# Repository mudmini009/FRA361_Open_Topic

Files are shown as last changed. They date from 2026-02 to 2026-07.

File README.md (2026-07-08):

---
# 🤖 MechAim-CV: Hardware-Based Physical Aimbot Using Computer Vision

A hardware-based robotic aimbot that uses real-time object detection (YOLOv5) to physically move a computer mouse. Built as an end-to-end exploration of Computer Vision, PID Control, and Inverse Kinematics.

Tested primarily in **Kovaak's Aim Trainer** to evaluate latency, tracking accuracy, and mechanical constraints without interfering with competitive multiplayer environments.

## 📺 Project Showcase

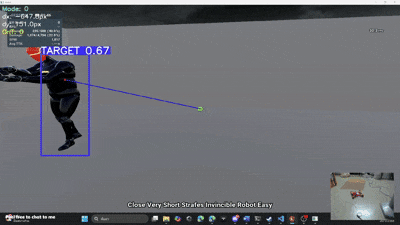
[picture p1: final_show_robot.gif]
Physical Aimbot Showcase


---

## 🚀 System Architecture

Unlike software-based aimbots, this system physically moves the mouse using a custom-built Mecanum-wheeled robot, bypassing traditional software anti-cheat mechanisms.

* **Vision System (PC):** Captures the screen, runs YOLOv5 object detection to find targets, and calculates pixel error `(dx, dy)` from the screen center.
* **Control System (PC):** A dual-axis PID controller processes the pixel error and computes the required linear velocities `(vx, vy)`. Inverse Kinematics (IK) then translates these velocities into specific speed commands for four Mecanum wheels.
* **Hardware Execution (ESP32):** The PC sends wheel speed data via Serial to an ESP32 microcontroller, which generates PWM signals for the DRV8833 motor drivers to move the physical mouse.
* **Clicking Mechanism (PC):** A Python script utilizes `pynput` to simulate realistic "pulse clicks" when the target is centered, reducing latency and simulating human input.

---

## 📁 Repository Structure

```text
📦 FRA361_Open_Topic
 ┣ 📂 archive/              # Legacy test scripts, early prototypes, and V1 learning logs
 ┣ 📂 CAD/                  # SolidWorks design files for the 3D-printed chassis
 ┣ 📂 Code_Program/         # MAIN WORKSPACE: Contains the Python vision loop & ESP32 firmware
 ┣ 📂 DATASET/              # (Ignored via .gitignore) Contains the custom 38k+ image training dataset
 ┣ 📂 documentation/        # Detailed academic reports, research papers, and reflection logs
 ┣ 📂 model_evaluation/     # Training results, confusion matrices, and metrics from Tesla V100 GPU runs
 ┣ 📂 models/               # Trained YOLOv5 weights (.pt) - Includes Small, Medium, and Large
 ┣ 📂 research_testing/     # Scripts for unit testing hardware, PWM deadzones, and software isolation
 ┣ 📜 .gitignore            # Keeps the repo clean of heavy datasets and __pycache__
 ┣ 📜 final show robot.mp4  # Showcase demonstration video
 ┣ 📜 hardware_bom.xlsx     # Bill of Materials (BOM) for the robotic chassis
 ┣ 📜 Presentation.pdf      # High-level slide deck summarizing the project engineering
 ┗ 📜 requirements.txt      # Python dependencies for the vision and control loop

```

---

## 🛠️ Getting Started

### 1. Prerequisites

* **Python 3.9+** (Tested on PyTorch 2.1 with CUDA 12.1 for RTX 3060).
* **PlatformIO** (For flashing the microcontroller).
* A generic ESP32 development board and 4x Yellow TT Motors with Mecanum wheels.

### 2. Software Installation

Clone the repository and install the required Python libraries using the provided requirements file:

```bash
git clone https://github.com/mudmini009/FRA361_Open_Topic.git
cd FRA361_Open_Topic
pip install -r requirements.txt

```

### 3. Hardware Setup (ESP32)

1. Navigate to `Code_Program/esp32/`.
2. Open the  `.cpp` firmware file in PlatformIO.
3. Connect your ESP32 via USB and upload the code.
4. Refer to `hardware_bom.xlsx` and the `CAD/` folder for assembly and wiring instructions.

### 4. Running the Aimbot

Ensure your Kovaak Aim Trainer window is open. Run the main execution loop:

```bash
cd Code_Program
python main.py

```

*Note: The script will prompt you to enter the name of the game window to bind the screen capture.*

---

## ⌨️ Controls & Modes

The system uses global keyboard hooks to allow mode switching even while the game is fully focused.

* **`Z`** : Quit application.
* **`X`** : Mode 0 (Idle / System Pause).
* **`C`** : Mode 1 (Aim Only - Tracks target but does not shoot).
* **`V`** : Mode 2 (Aim + Pulse Click - Tracks and automatically fires).

---

## 🧠 AI Models

The `models/` folder contains custom-trained YOLOv5 weights evaluated on a Tesla V100 server.

* **YOLOv5s (Small):** Best for high-speed tracking (~15ms inference).
* **YOLOv5m (Medium):** The recommended balance of accuracy and latency for PID tracking.
* **YOLOv5l (Large):** High precision, but introduces latency.
* *(Note: The YOLOv5x (X-Large) model was omitted from this repository due to file size limits and significant latency impacts >30ms that bottlenecked physical robot control)*.

---

🎓 Engineering & Academic Context

This system was originally developed and engineered as part of the **FRA361 - Open Topics** coursework within the Institute of Field Robotics (FIBO). Extensive research documentation regarding the physical prototyping iterations, empirical PWM deadzone calibrations, and dataset augmentation metrics can be found inside the `documentation/` folder and the accompanying `Presentation.pdf`.

* **Lead Engineer:** Pollapaat Suttimala
---

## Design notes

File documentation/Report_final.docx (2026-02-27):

Physical Aimbot สำหรับเกม FPS ด้วย Computer Vision

นายภนลภัส สุทธิมาลา รหัศนักศึกษา 65340500046

โครงงานนี้เป็นส่วนหนึ่งของการศึกษาตามหลักสูตร

ปริญญาวิศวกรรมศาสตรบัณฑิต สาขาวิชาวิศวกรรมหุ่นยนต์และระบบอัตโนมัติ

สถาบันวิทยาการหุ่นยนต์ภาคสนาม

มหาวิทยาลัยเทคโนโลยีพระจอมเกล้าธนบุรี

ปีการศึกษา 2567

Source Code Repository : https://github.com/mudmini009/FRA361_Open_Topic.git

# บทที่ 1 บทนำ

## 1.1 ที่มา ความสำคัญ

ในปัจจุบันเกมแนว First-Person Shooter (FPS) เป็นประเภทเกมที่ได้รับความนิยมสูง ผู้เล่นส่วนมากให้ความสำคัญกับการเล็งเป้าที่รวดเร็วและแม่นยำ ซึ่งนำไปสู่การพัฒนาเครื่องมือหรือโปรแกรมต่าง ๆ ในการฝึกฝนทักษะการเล็ง เช่น Aim Training Software เป็นต้น อย่างไรก็ตาม กระบวนการฝึกเล็งดังกล่าวยังต้องอาศัยการขยับเมาส์ของผู้เล่นเองเป็นหลัก ซึ่งอาจเกิดข้อจำกัดด้านความแม่นยำและความสม่ำเสมอในการเคลื่อนที่ของมือมนุษย์

โครงงานนี้จึงมีแนวคิดในการพัฒนาระบบ "Physical Aimbot" โดยนำหลักการทางด้านวิศวกรรมหุ่นยนต์ (Robotics) และการประมวลผลภาพ (Computer Vision) มาผสมผสานกัน เพื่อสร้างหุ่นยนต์ที่สามารถควบคุมเมาส์จริงบนพื้นผิวจริงได้อย่างแม่นยำและอัตโนมัติ ผ่านการตรวจจับตำแหน่งเป้าหมายบนหน้าจอจากภาพหรือวิดีโอที่ประมวลผลด้วยโมเดล Machine Learning ประเภท Object Detection เช่น YOLO (You Only Look Once) โดยมีวัตถุประสงค์หลักคือ เพื่อศึกษาความเป็นไปได้ในการผสานเทคโนโลยีหุ่นยนต์และ Computer Vision รวมทั้งสร้างความรู้พื้นฐานและประสบการณ์ในการออกแบบและพัฒนาระบบที่มีทั้งองค์ประกอบทางด้าน Software และ Hardware มากกว่าจะมุ่งเน้นการนำไปใช้เพื่อประโยชน์เชิงแข่งขันหรือเชิงโกงภายในเกม

## 1.2 ประโยคปัญหางานวิจัย (Problem Statement)

ในการเล็งเป้าหมายในเกม FPS หรือโปรแกรมฝึกเล็งที่ต้องการความแม่นยำสูง ผู้เล่นมักประสบปัญหาในการควบคุมการเคลื่อนที่ของเมาส์ให้แม่นยำและรวดเร็ว เนื่องจากการปรับมุมและตำแหน่งของเมาส์ซ้ำ ๆ ส่งผลให้เสียเวลาและลดประสิทธิภาพในการเล่น โครงงานนี้จึงมุ่งสำรวจและพัฒนาระบบการควบคุมการเคลื่อนที่ของเมาส์ด้วยกลไกหุ่นยนต์และการประมวลผลภาพ (Computer Vision) แบบเรียลไทม์ เพื่อสร้างระบบช่วยเล็งที่สามารถตรวจจับเป้าหมายบนหน้าจอและสั่งให้หุ่นยนต์เคลื่อนที่เมาส์ให้ตรงตามเป้าหมายได้อย่างแม่นยำและอัตโนมัติ ทั้งนี้เพื่อเพิ่มความต่อเนื่องในการเล่นและเป็นการศึกษาการผสานเทคโนโลยี Robotics กับ Computer Vision ให้เกิดเป็นรูปธรรม

## 1.3 ผลผลิตและผลลัพธ์ (Outputs and Outcomes)

### ผลผลิต

1. ต้นแบบหุ่นยนต์ (Robot Prototype) ที่สามารถควบคุมและเคลื่อนที่ของเมาส์จริงบนพื้นผิว เพื่อเล็งไปยังตำแหน่งเป้าหมายที่ระบุจากระบบตรวจจับภาพ

2. โมเดล Machine Learning (YOLO-based Object Detection Model) ที่สามารถตรวจจับและระบุตำแหน่งเป้าหมายจากภาพหรือวิดีโอแบบเรียลไทม์ ในโปรแกรมฝึกเล็ง (Aim Training Software) หรือเกม FPS

### ผลลัพธ์

1. ความรู้และความเข้าใจเชิงลึก เกี่ยวกับการผสมผสานระหว่างเทคโนโลยี Robotics และ Computer Vision ในการประยุกต์ใช้สำหรับการควบคุมอุปกรณ์เชิงกายภาพ

2. แนวทางหรือกรอบการทำงาน (Framework) ในการพัฒนาระบบช่วยเล็งแบบกายภาพ (Physical Aiming Assistant) ที่สามารถนำไปต่อยอดหรือปรับปรุงในการศึกษาหรือวิจัยอื่น ๆ ในอนาคตได้

## 1.4 ความต้องการของระบบ (Requirements)

1. ระบบต้องสามารถจับภาพหน้าจอหรือรับข้อมูลจากโปรแกรมฝึกเล็งใน Kovaak โดยใช้ Python library สำหรับการจับภาพ เพื่อระบุพิกัดเป้าหมาย

2. ระบบหุ่นยนต์ต้องสามารถเคลื่อนที่ได้อย่างมีประสิทธิภาพในการเล็งและปรับตำแหน่งเมาส์ตามข้อมูลที่ได้รับ โดยใช้มอเตอร์แบบ Yellow TT motor ที่ติดกับล้อ Mecanum

3. ในอนาคตจะพัฒนาโมดูลสำหรับการส่งสัญญาณคลิก โดยใช้การสื่อสารผ่าน ESP32 Bluetooth ที่เชื่อมต่อกับ PC เพื่อส่งข้อมูลการคลิก

4. ใช้ซอฟต์แวร์และฮาร์ดแวร์ที่หาได้ทั่วไป เช่น Logitech G Pro X Superlight, ESP32 สำหรับการสื่อสาร Bluetooth, และ Python library สำหรับการจับภาพหน้าจอ (แทนการใช้ Capture Card)

## 1.5 ขอบเขตของงานวิจัย (Scopes)

1.ใช้โปรแกรมฝึกเล็ง (Kovaak) เป็นหลักในการเก็บข้อมูลภาพหรือวิดีโอ เพื่อนำมาประมวลผลด้วยโมเดล Machine Learning ในการระบุตำแหน่งเป้าหมาย

2.มุ่งเน้นการทดสอบประสิทธิภาพของระบบ โดยวัดผลจากคะแนน (Score) ที่ได้จากแต่ละ Scenario ในโปรแกรม Kovaak เป็นหลัก เช่น คะแนนรวม (Total Score), ความแม่นยำ (Accuracy), เปอร์เซ็นต์การยิงโดน (Percent Hit), จำนวนเป้าหมายที่ยิงโดน (Targets Hit), จำนวนเป้าหมายที่พลาด (Targets Missed), และข้อมูลเชิงสถิติอื่นๆ ที่โปรแกรมมีให้ เพื่อศึกษาความสามารถในการเล็งเป้าของระบบหุ่นยนต์อย่างชัดเจนและวัดผลได้

3.ในขั้นนี้จะยังไม่เน้นเก็บสถิติเรื่องความเร็วในการตอบสนอง (Latency) หรือรายละเอียดด้านเวลาเป็นหลัก

4.โครงงานนี้มีจุดประสงค์เพื่อศึกษาและพัฒนาองค์ความรู้ในการประยุกต์ใช้ Robotics และ Computer Vision เท่านั้น ไม่มีเจตนาที่จะนำไปใช้งานเพื่อประโยชน์เชิงแข่งขันจริงหรือเพื่อการโกงเกม

## 1.6 ข้อกำหนดของงานวิจัย (Assumptions)

1. สภาพแวดล้อม (Environment) ที่ใช้ในการทดสอบ เช่น ความละเอียดหน้าจอ (Screen Resolution) และการตั้งค่ากราฟิก (Graphic Settings) ในโปรแกรม Kovaak จะถูกกำหนดให้มีค่าคงที่และไม่เปลี่ยนแปลงตลอดช่วงการทดลอง เพื่อความสม่ำเสมอในการเก็บข้อมูล

2. ผู้วิจัยสามารถปรับค่าความไวของเมาส์ (Mouse Sensitivity) และการตั้งค่าอื่น ๆ ที่เกี่ยวข้องได้ตามความเหมาะสม เพื่อให้ตรงกับเงื่อนไขและความต้องการในการทดลองร่วมกับโปรแกรม Kovaak

## 1.7 ขั้นตอนการดำเนินงาน

1. เก็บข้อมูลและสร้าง Dataset

1.1. บันทึกการเล่นโปรแกรม Kovaak (Scenarios ต่างๆ เช่น Tracking และ Dynamic Clicking)

1.2. ใช้ OpenCV ดึงภาพจากวิดีโอที่บันทึกไว้ นำไปทำ Label และ Augmentation

2. พัฒนาและฝึกโมเดล Machine Learning

2.1. บันทึกการเล่นโปรแกรม Kovaak (Scenarios ต่างๆ เช่น Tracking และ Dynamic Clicking)

2.2. ใช้ OpenCV ดึงภาพจากวิดีโอที่บันทึกไว้ นำไปทำ Label และ Augmentation

3. ศึกษาและคัดเลือกฮาร์ดแวร์

3.1. สำรวจตัวเลือกและตัดสินใจเลือกใช้ล้อ Mecanum และมอเตอร์ประเภท Yellow TT motor เนื่องจากข้อจำกัดด้านงบประมาณ

3.2. ออกแบบระบบจ่ายไฟโดยใช้แบตเตอรี่ 18650 สองก้อน พร้อมวงจรควบคุมแรงดัน (XL4016E1)

4. ออกแบบและเขียนแบบ CAD

4.1. ออกแบบโครงสร้างหุ่นยนต์และส่วนยึดอุปกรณ์ทั้งหมด โดยใช้โปรแกรม CAD เพื่อจัดวางตำแหน่งของมอเตอร์, ล้อ, ESP32 และส่วนประกอบอื่นๆ

5. สร้างต้นแบบหุ่นยนต์ (Prototype)

5.1. ประกอบวงจรและอุปกรณ์ต่างๆ ตามแบบ CAD

5.2. ทดลองระบบเบื้องต้นเพื่อทดสอบการเคลื่อนที่ของหุ่นยนต์ (ยังไม่รวมการเชื่อมต่อกับระบบ Software)

6. ผสานระบบ (Integration)

6.1. เขียนโปรแกรม Python เพื่อจับภาพหน้าจอจากโปรแกรม Kovaak แล้วส่งไปยังโมเดล YOLOv5 ที่ฝึกไว้

6.2. ส่งค่าตำแหน่งเป้าหมายที่ได้จากการตรวจจับไปยัง ESP32 ผ่าน PySerial เพื่อควบคุมการเคลื่อนที่ของหุ่นยนต์

6.3. ใช้ ESP32 Bluetooth ส่งข้อมูลคลิกกลับไปยัง PC (พัฒนาเพิ่มเติมในอนาคต)

7. ทดสอบและปรับแต่งระบบ

7.1. ทดสอบการทำงานจริงโดยวัดผลจากคะแนน (Scores) และความแม่นยำ (Accuracy) จาก Kovaak

7.2. วิเคราะห์ผลเบื้องต้น และวางแผนเพิ่มประสิทธิภาพ เช่น การปรับปรุง Dataset, การ Train โมเดลเพิ่มเติม, หรือปรับแต่ง Hardware

# บทที่ 2 ทฤษฎี/งานวิจัย/การศึกษาที่เกี่ยวข้อง

## 2.1Computer Vision สำหรับ Object Detection

การตรวจจับวัตถุ (Object Detection) เป็นเทคนิคในวิทยาการคอมพิวเตอร์ที่ใช้ในการระบุและกำหนดตำแหน่งของวัตถุภายในภาพหรือวิดีโอ โดยทั่วไปจะใช้กรอบสี่เหลี่ยมล้อมรอบวัตถุที่ตรวจพบ

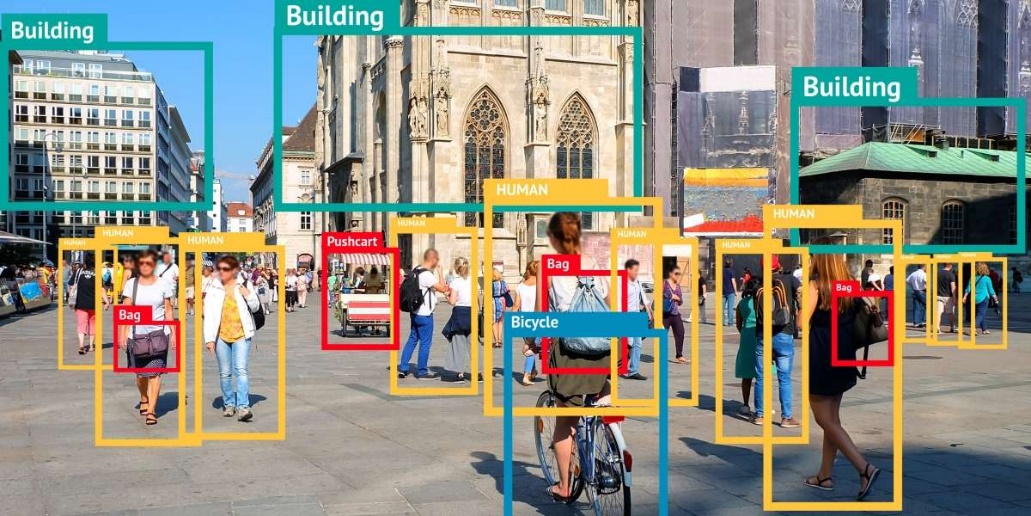
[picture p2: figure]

### 2.1.1 หลักการทำงานพื้นฐานของ YOLO (You Only Look Once)

YOLO ทำงานโดยแบ่งภาพอินพุตออกเป็นกริดขนาด S x S และสำหรับแต่ละเซลล์ในกริดนั้น โมเดลจะทำนาย B กล่องขอบเขต (bounding boxes) พร้อมกับคะแนนความเชื่อมั่น (confidence scores) ที่บ่งบอกถึงความน่าจะเป็นที่กล่องนั้นจะมีวัตถุอยู่ และความแม่นยำของกล่องที่ทำนาย นอกจากนี้ แต่ละเซลล์ยังทำนายความน่าจะเป็นแบบมีเงื่อนไขสำหรับแต่ละคลาสของวัตถุ โดยอิงตามความน่าจะเป็นที่เซลล์นั้นมีวัตถุอยู่ การทำนายทั้งหมดนี้เกิดขึ้นพร้อมกันในการประมวลผลเพียงครั้งเดียว ทำให้ YOLO มีความเร็วสูงในการตรวจจับวัตถุ

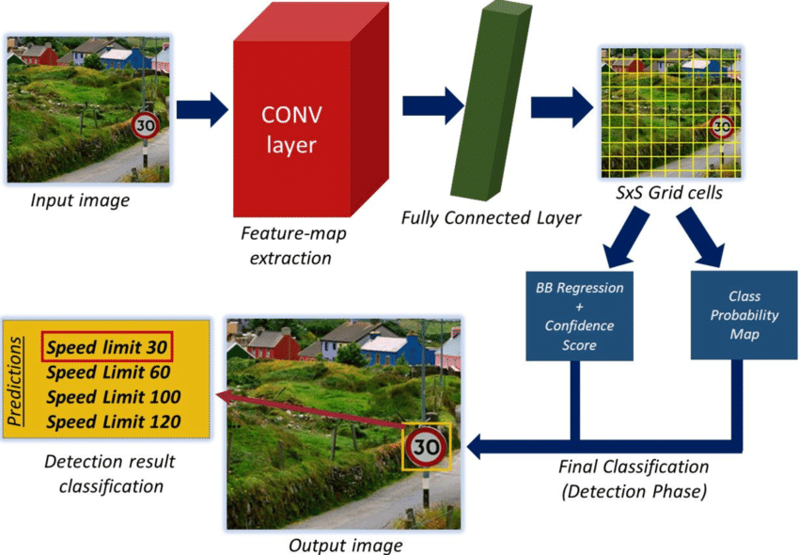
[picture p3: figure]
Object detection and classification process in YOLO. | Download Scientific Diagram

1. โครงสร้างโมเดล YOLO

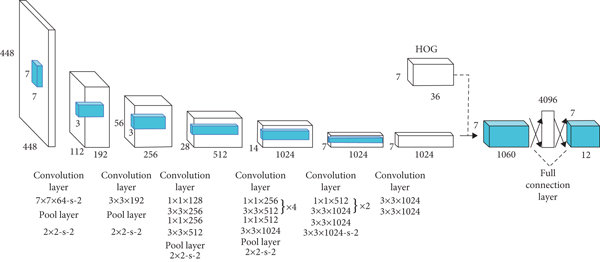
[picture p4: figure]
Yolo model convolution layer network structure diagram. | Download Scientific Diagram

โครงสร้างของ YOLO ประกอบด้วยเลเยอร์คอนโวลูชันหลายชั้นที่ใช้ในการดึงคุณลักษณะจากภาพอินพุต ตามด้วยเลเยอร์ที่เชื่อมต่อกันอย่างสมบูรณ์ (fully connected layers) ที่ใช้ในการทำนายตำแหน่งของกล่องขอบเขตและความน่าจะเป็นของคลาสวัตถุ โครงสร้างนี้ช่วยให้โมเดลสามารถเรียนรู้การแทนภาพในระดับสูงและทำการทำนายได้อย่างแม่นยำ

2. กระบวนการตรวจจับภาพและหลักการทำงานของ YOLO

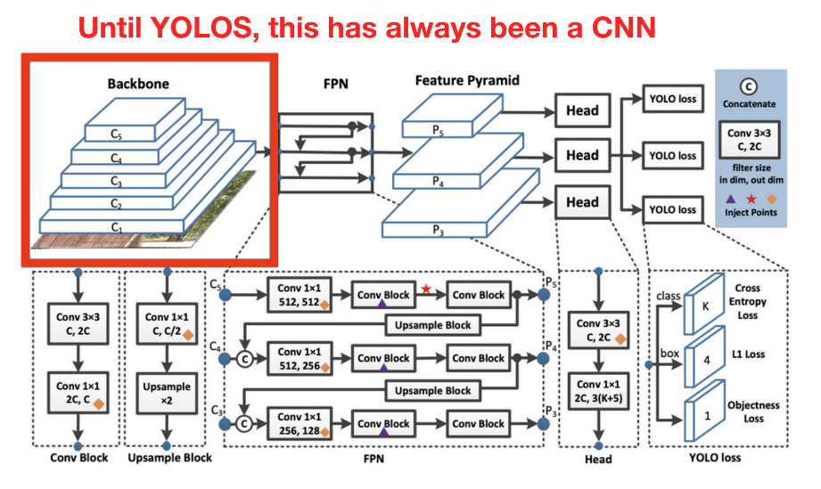
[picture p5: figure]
What is YOLOS? What's New in the Model?

  a. การแบ่งภาพเป็นกริด: ภาพอินพุตจะถูกแบ่งออกเป็นกริดขนาด S x S โดยแต่ละเซลล์ในกริดจะรับผิดชอบในการทำนายวัตถุที่มีศูนย์กลางอยู่ในเซลล์นั้น
  b. การทำนายกล่องขอบเขตและคะแนนความเชื่อมั่น: สำหรับแต่ละเซลล์ โมเดลจะทำนาย กล่องขอบเขต พร้อมกับคะแนนความเชื่อมั่นที่บ่งบอกถึงความน่าจะเป็นที่กล่องนั้นจะมีวัตถุอยู่ และความแม่นยำของกล่องที่ทำนาย
  c. การทำนายความน่าจะเป็นของคลาสวัตถุ: โมเดลจะทำนายความน่าจะเป็นแบบมีเงื่อนไขสำหรับแต่ละคลาสของวัตถุ โดยอิงตามความน่าจะเป็นที่เซลล์นั้นมีวัตถุอยู่
  d. การคูณคะแนนความเชื่อมั่นกับความน่าจะเป็นของคลาส: คะแนนความเชื่อมั่นจะถูกคูณกับความน่าจะเป็นของคลาสเพื่อให้ได้คะแนนสุดท้ายสำหรับแต่ละกล่องขอบเขต
  e. การกรองกล่องขอบเขต: ใช้เทคนิค Non-Maximum Suppression (NMS) เพื่อลบกล่องขอบเขตที่ซ้ำซ้อนและเก็บเฉพาะกล่องที่มีคะแนนสูงสุดสำหรับแต่ละวัตถุ

### 2.1.2 การเปรียบเทียบรุ่น YOLO (YOLO Version Comparison)

ในงานนี้ เราเน้นการใช้โมเดล YOLOv5 ซึ่งมีหลายเวอร์ชันที่แตกต่างกันในเรื่องของขนาดและประสิทธิภาพ เราสามารถแบ่งเวอร์ชันหลัก ๆ ได้ดังนี้:

1. YOLOv5s (Small)
  - ข้อดี:
    - มีขนาดเล็ก ใช้ทรัพยากรน้อย
    - ประมวลผลได้รวดเร็ว เหมาะกับงานที่ต้องการการตอบสนองแบบเรียลไทม์ เช่น การตรวจจับเป้าหมายในโปรแกรม Aim Training (Kovaak)
  - ข้อเสีย:
    - ความแม่นยำอาจต่ำกว่าเมื่อเทียบกับเวอร์ชันที่มีขนาดใหญ่กว่า
2. YOLOv5m (Medium)
  - ข้อดี:
    - ให้ความแม่นยำสูงขึ้นจาก YOLOv5s ด้วยจำนวนพารามิเตอร์ที่เพิ่มขึ้น
    - ยังสามารถประมวลผลแบบเรียลไทม์ได้ดีในระบบที่มีฮาร์ดแวร์ประสิทธิภาพสูง
  - ข้อเสีย:
    - ใช้ทรัพยากรมากขึ้น และอาจมีความช้ากว่า YOLOv5s เล็กน้อย
3. YOLOv5l (Large) และ YOLOv5x (Extra Large)
  - ข้อดี:
    - ให้ความแม่นยำสูงสุด เนื่องจากมีจำนวนพารามิเตอร์มากที่สุด
  - ข้อเสีย:
    - ประมวลผลช้ากว่าและต้องการทรัพยากรระบบที่สูงขึ้น ซึ่งอาจไม่เหมาะกับงานที่ต้องการความเร็วแบบเรียลไทม์ในสภาพแวดล้อมที่มีข้อจำกัดด้านทรัพยากร

สำหรับโครงการนี้ เราเริ่มต้นด้วย YOLOv5s (Small) เนื่องจากมีความเร็วสูงและเหมาะสมกับการทดลองเบื้องต้นในระบบ Aim Training (Kovaak) อย่างไรก็ตาม ด้วยประสิทธิภาพของ PC ที่มีอยู่ (สามารถรันได้ 200+ FPS) ในอนาคตจึงมีความเป็นไปได้ที่จะปรับปรุงและฝึกเพิ่มเติมโดยพิจารณาให้เหมาะสมกับข้อจำกัดของฮาร์ดแวร์และลักษณะของงาน เช่น หากต้องการตรวจจับอย่างรวดเร็วและใช้งานร่วมกับระบบที่มีข้อจำกัดด้าน latency อาจเลือกใช้ YOLOv5s หรือ m ในขณะที่หากระบบสามารถรองรับการประมวลผลที่ช้าลงได้และต้องการความแม่นยำสูง YOLOv5l หรือ x ก็เป็นทางเลือกที่เหมาะสม

## 2.2 Robotics และการควบคุมการเคลื่อนที่

### 2.2.1 Omni Wheels และ Mecanum Wheels

ในการออกแบบระบบเคลื่อนที่สำหรับหุ่นยนต์ที่ควบคุมเมาส์ในงาน Physical Aimbot มีล้อสองแบบที่มักถูกนำมาใช้ ได้แก่ Omni Wheels และ Mecanum Wheels:

  - Omni Wheels:
    - หลักการ: ล้อ Omni มีแผ่นสัมผัสที่สามารถหมุนได้ในแนวตั้งและมีล้อเล็กติดอยู่รอบๆ ซึ่งช่วยให้เคลื่อนที่ได้ในทิศทางหลายทิศทาง
    - ข้อดี: ให้ความสามารถในการเคลื่อนที่แบบ holonomic (เคลื่อนที่ในทุกทิศทาง)
    - ข้อเสีย: โดยทั่วไปราคาแพงกว่าแบบอื่นถึง 4–5 เท่า ทำให้ไม่เหมาะสำหรับงานที่มีข้อจำกัดด้านงบประมาณ
  - Mecanum Wheels:
    - หลักการ: ล้อ Mecanum มีลูกกลิ้งติดอยู่ที่ขอบล้อในมุมเอียง ช่วยให้สามารถเคลื่อนที่แบบ omnidirectional ได้ด้วยการควบคุมความเร็วของแต่ละล้อแยกกัน
    - ข้อดี: ราคาถูกกว่า Omni Wheels อย่างมาก, ให้ความสามารถในการเคลื่อนที่แบบหลายทิศทางได้ดีเพียงพอสำหรับงานควบคุมเมาส์ในระบบ Physical Aimbot
    - ข้อเสีย: การควบคุมอาจซับซ้อนกว่าเล็กน้อยเนื่องจากต้องคำนวณการเคลื่อนที่ที่สัมพันธ์กันของล้อทั้งหมด

สาเหตุที่เลือก Mecanum Wheels:

เนื่องจากข้อจำกัดด้านงบประมาณ โดย Omni Wheels มีราคาสูงถึง 4–5 เท่าของ Mecanum Wheels ทำให้การเลือกใช้ Mecanum Wheels เป็นทางเลือกที่ประหยัดและยังคงให้ประสิทธิภาพในการเคลื่อนที่ที่เพียงพอสำหรับการควบคุมเมาส์ในโครงงานนี้

### 2.2.2 ทฤษฎี Inverse Kinematics สำหรับล้อ Mecanum

การควบคุมการเคลื่อนที่ในหุ่นยนต์ที่ใช้ล้อ Mecanum ต้องอาศัยหลักการของ Inverse Kinematics ซึ่งเป็นการคำนวณหาความเร็วและทิศทางของแต่ละล้อจากคำสั่งการเคลื่อนที่ที่ต้องการ (เช่น การเล็งเป้าหมาย)

- หลักการคำนวณ: สำหรับหุ่นยนต์ที่ใช้ล้อ Mecanum จำนวน 4 ตัว เราสามารถคำนวณความเร็วของแต่ละล้อจากความต้องการเคลื่อนที่ในแกน X (Vx), แกน Y (Vy) และการหมุน (angular velocity, ω) ได้ดังนี้:
  - ความเร็วล้อหน้าซ้าย (V_FL) = Vx - Vy - (L + W) * ω
  - ความเร็วล้อหน้าขวา (V_FR) = Vx + Vy + (L + W) * ω
  - ความเร็วล้อหลังซ้าย (V_RL) = Vx + Vy - (L + W) * ω
  - ความเร็วล้อหลังขวา (V_RR) = Vx - Vy + (L + W) * ω โดยที่:
    - Vx: ความเร็วในแนวแกน X
    - Vy: ความเร็วในแนวแกน Y
    - ω: ความเร็วเชิงมุม (การหมุน)
    - L: ระยะจากจุดศูนย์กลางไปยังล้อในแนวตั้ง
    - W: ระยะจากจุดศูนย์กลางไปยังล้อในแนวนอน
- แนวคิดเบื้องต้นในการควบคุม: เมื่อระบบ Computer Vision ตรวจจับเป้าหมายแล้ว ระบบจะคำนวณตำแหน่งเป้าหมายที่ต้องเล็ง จากนั้นใช้ Inverse Kinematics ในการแปลงคำสั่งเคลื่อนที่ (เช่น ค่า Vx, Vy, ω) ไปเป็นความเร็วที่แต่ละล้อควรหมุนเพื่อให้หุ่นยนต์เคลื่อนที่ไปในทิศทางที่ต้องการได้อย่างแม่นยำ การคำนวณเหล่านี้ช่วยให้ระบบสามารถปรับตำแหน่งเมาส์ให้ตรงกับเป้าหมายได้โดยอัตโนมัติ

### 2.2.3 PID Controller สำหรับการควบคุมความเร็วของมอเตอร์

ในการควบคุมความเร็วหรือทิศทางของมอเตอร์ให้แม่นยำในระบบหุ่นยนต์ มักนิยมใช้ PID Controller (Proportional–Integral–Derivative) ซึ่งเป็นการควบคุมแบบ Feedback ที่สามารถลดความคลาดเคลื่อน (error) ระหว่าง "ค่าที่ต้องการ" (Setpoint) และ "ค่าที่เกิดขึ้นจริง" (Measured Value) ได้อย่างมีประสิทธิภาพ

แนวคิดพื้นฐานของ PID

PID ประกอบด้วยสามส่วนหลัก ดังนี้:

- P (Proportional): เป็นส่วนที่ตอบสนองต่อค่า error ปัจจุบัน โดยมีค่าสัดส่วนเป็นตัวคูณ P_out = Kp * e(t)
- I (Integral): เป็นส่วนที่รวมสะสมค่า error ย้อนหลัง เพื่อกำจัดค่า steady-state error I_out = Ki * ∫ e(t) dt
- D (Derivative): เป็นส่วนที่ตอบสนองต่อการเปลี่ยนแปลงของ error เพื่อช่วยลดการ overshoot และทำให้ระบบมีความเสถียรมากขึ้น

D_out = Kd * de(t)/dt

ผลรวมของทั้งสามส่วนคือสัญญาณควบคุมที่ใช้ส่งไปยังมอเตอร์:

u(t) = P_out + I_out + D_out

หรือรวมในสมการเดียว:

u(t) = Kp * e(t) + Ki * ∫ e(t) dt + Kd * de(t)/dt

โดยที่:

- u(t) = ค่าคำสั่งควบคุมที่ส่งออก
- e(t) = ค่า error = ค่าที่ต้องการ - ค่าที่วัดได้
- Kp, Ki, Kd = ค่าพารามิเตอร์ของ PID ซึ่งต้องทำการจูนให้เหมาะสมกับระบบ

การประยุกต์ใช้กับโครงงาน Physical Aimbot

ในโครงงานนี้ PID ถูกออกแบบมาเพื่อใช้ควบคุม ความเร็วของมอเตอร์แต่ละตัว เพื่อเคลื่อนที่หุ่นยนต์ให้ไปยังตำแหน่งที่ตรวจจับได้จากระบบ Vision โดยมีขั้นตอนดังนี้:

1. ระบบตรวจจับภาพจะระบุ ตำแหน่งเป้าหมาย (Target) บนหน้าจอ
2. คำนวณตำแหน่งเป้าหมายเทียบกับจุดศูนย์กลางของหน้าจอ เพื่อหา ค่าความคลาดเคลื่อน (error) ทั้งในแนวระยะ (Distance) และมุม (Angle)
3. นำค่า error ที่ได้เข้าสู่ฟังก์ชัน PID เพื่อคำนวณ "ความเร็วของแต่ละล้อ" ที่จะทำให้หุ่นยนต์เคลื่อนที่เข้าหาเป้าหมายอย่างแม่นยำ

ระบบนี้สามารถใช้ distance เป็นค่าความห่างจากเป้าหมาย และ angle เป็นทิศทางเปรียบเทียบกับแนวตั้งฉากของหุ่นยนต์ ทำให้สามารถนำทั้งสองค่ามาควบคุม PID แบบแยกแกนได้ หรือแบบรวมก็ได้ ขึ้นอยู่กับกลยุทธ์การควบคุม

การตั้งค่าพารามิเตอร์ PID (PID Tuning)

การตั้งค่าค่า Kp, Ki, Kd ที่เหมาะสมเป็นขั้นตอนที่สำคัญมาก โดยวิธีที่นิยมคือ Manual Tuning หรือ "trial-and-error" โดย:

1. เริ่มจาก Ki และ Kd = 0
2. เพิ่ม Kp ทีละน้อยจนระบบเริ่มตอบสนอง
3. เพิ่ม Ki เพื่อแก้ปัญหา steady-state error
4. เพิ่ม Kd เพื่อช่วยลด overshoot และเพิ่มความเสถียร

ในกรณีของโครงงานนี้ เนื่องจากไม่มี encoder feedback เพื่อวัดความเร็วของล้อจริง จึงมีการใช้ “distance to target” หรือ “angle to target” จาก Vision เป็น input แทน โดยจะต้องสังเกตพฤติกรรมของหุ่นยนต์เพื่อทำการจูนค่า PID ให้เหมาะสม

## 2.3 Hardware และการสื่อสารข้อมูล

### 2.3.1 ESP32 Microcontroller

เราเลือกใช้ ESP32 เนื่องจากมีคุณสมบัติที่โดดเด่นหลายประการที่สอดคล้องกับความต้องการของโครงงานนี้

- ความเร็วและประสิทธิภาพสูง: ESP32 สามารถประมวลผลคำสั่งและสื่อสารได้อย่างรวดเร็ว ทำให้รองรับงานที่ต้องการการตอบสนองแบบเรียลไทม์
- การเชื่อมต่อแบบ WiFi และ Bluetooth: การมีทั้ง WiFi และ Bluetooth ในตัวช่วยให้เราสามารถเชื่อมต่อกับ PC ผ่าน WiFi หรือใช้ Bluetooth สำหรับส่งคำสั่งการคลิกโดยตรง ซึ่งจะช่วยลดความซับซ้อนของโมดูลคลิกแยกต่างหาก
- ความยืดหยุ่นในการประมวลผล Inverse Kinematics: ระบบสามารถเลือกที่จะคำนวณ Inverse Kinematics บนตัว ESP32 เอง หรือรับค่าที่คำนวณจาก PC (เช่น ค่า Distance, Degree และ Shooting command) ขึ้นอยู่กับประสิทธิภาพของแต่ละหน่วย เราสามารถปรับเปลี่ยนวิธีการส่งข้อมูลได้โดยพิจารณาจากความเร็วในการคำนวณของ PC เทียบกับ ESP32

### 2.3.2 การสื่อสารข้อมูลผ่าน PySerial

สำหรับการส่งข้อมูลระหว่างคอมพิวเตอร์และ ESP32 เราใช้การสื่อสารผ่าน PySerial ด้วยข้อดีดังนี้:

- การเชื่อมต่อที่ง่าย: PySerial ช่วยให้การส่งข้อมูลระหว่าง PC กับ ESP32 เป็นไปอย่างราบรื่น โดยไม่ต้องใช้ฮาร์ดแวร์เพิ่มเติม
- ประเภทของข้อมูลที่ส่ง:
  - Distance: ระยะห่างระหว่างตำแหน่งปัจจุบันกับเป้าหมายที่คำนวณได้
  - Degree: มุมที่เป้าหมายอยู่ในระบบพิกัด
  - Shooting Command: คำสั่งยิงที่จะส่งไปยัง ESP32 เมื่อเป้าหมายอยู่ในขอบเขตที่กำหนด
- กระบวนการส่งข้อมูล:
  - หากการคำนวณ Inverse Kinematics ถูกดำเนินการบน PC เราจะส่งข้อมูลที่คำนวณแล้ว (Distance, Degree) พร้อมกับคำสั่งยิง (Shooting command) ไปยัง ESP32
  - ในทางกลับกัน หาก ESP32 มีความสามารถในการคำนวณ Inverse Kinematics ได้เร็วเพียงพอ ระบบจะรับข้อมูลพื้นฐานจาก PC (เช่น ตำแหน่งเป้าหมาย) แล้วคำนวณค่า Distance, Degree และตัดสินใจส่งคำสั่งยิงภายในตัวเอง

### 2.3.3 Motor และ Driver

ในการขับเคลื่อนระบบหุ่นยนต์ เราเลือกใช้ Yellow TT Motor ร่วมกับ DRV8833 Motor Driver ด้วยเหตุผลดังนี้:

- Yellow TT Motor:
  - ร้านค้าที่มีจำหน่ายมีให้เลือกเพียง 2 แบบคือ 1:150 และ 1:48 สำหรับเกียร์
  - เนื่องจากหุ่นยนต์ของเราเบา (ใช้สำหรับเคลื่อนที่เมาส์ที่มีน้ำหนักต่ำ) เราจึงเลือกใช้เกียร์ 1:48 เพื่อให้ได้ความเร็วที่สูงขึ้น แม้ว่าแรงบิด (torque) จะน้อยลง แต่สำหรับงานนี้ ความเร็วในการตอบสนองและการเคลื่อนที่เป็นสิ่งที่สำคัญกว่า
  - โดยจาก Datasheet ของร้านค้า Yellow TT Motor 1:48 มีค่าแรงบิดประมาณ 1.5 kg⋅cm ซึ่งเมื่อนำมาคำนวณเป็นแรงขับเคลื่อนบนพื้นราบ สามารถวิเคราะห์ได้ดังนี้:

การประมาณแรงขับเคลื่อน (Force Calculation):

Torque (τ) = 1.5 kg⋅cm = 0.147 N⋅m
รัศมีล้อ (r) = 48 mm / 2 = 0.024 m
แรง (F) ที่ปลายล้อ = τ / r
= 0.147 / 0.024 ≈ 6.125 N ต่อล้อ

หากใช้ล้อทั้ง 4 ล้อขับเคลื่อนพร้อมกัน:

แรงรวม ≈ 4 × 6.125 = 24.5 N

และจากสมการ F = ma ⇒ a = F/m

การประมาณน้ำหนักหุ่นยนต์:

องค์ประกอบ | ประมาณน้ำหนัก
เมาส์ Logitech G Pro X | ~70 g
แบตเตอรี่ 18650 × 2 | ~90 g
ESP32 + XL4016 | ~40 g
โครง 3D print + มอเตอร์ | ~300 g
รวม | ~500 g (0.5 kg)

น้ำหนักหุ่นยนต์ประมาณ 0.5 kg ⇒ ต้องการแรงเพื่อเริ่มเคลื่อนที่ ≈ μmg
โดยที่:

μ = ค่าสัมประสิทธิ์แรงเสียดทานระหว่าง mouse feet กับพื้น ≈ 0.3–0.5 (Corepad Air)

g = 9.81 m/s²

⇒ F_friction ≈ 0.4 × 0.5 × 9.81 ≈ 1.96 N

เมื่อเทียบกับแรงขับเคลื่อน ≈ 24.5 N (รวมทุกล้อ)
→ มีแรงมากเพียงพอในทางทฤษฎี สำหรับการเคลื่อนที่ แม้จะเผื่อการสูญเสียในระบบ

- DRV8833 Motor Driver:
  - เป็นตัวควบคุมมอเตอร์ที่มีขนาดกะทัดรัด น้ำหนักเบา และรองรับการทำงานของมอเตอร์ในระดับแรงดันที่เหมาะสมสำหรับระบบของเรา

### 2.3.3.1 ข้อสังเกตเพิ่มเติมจากการใช้งานจริงของมอเตอร์ Yellow TT (1:48)

ผู้วิจัยจึงตัดสินใจเลือกใช้ มอเตอร์เกียร์ 1:48 เนื่องจากตัวหุ่นยนต์มีน้ำหนักรวมไม่มาก (ใช้เพียงเมาส์, ESP32, แบตเตอรี่ และโครงพลาสติก) โดยมีเป้าหมายให้หุ่นยนต์สามารถตอบสนองต่อคำสั่งเล็งเป้าได้เร็วและลื่นไหล

อย่างไรก็ตาม จากการทดสอบจริงในระยะหลัง พบว่าอัตราทด 1:48 อาจ ไม่เหมาะสมในด้านความแม่นยำในความเร็วต่ำ เพราะล้อจะเริ่มหมุนเมื่อได้รับแรงมากพอเท่านั้น เนื่องจากแรงบิดเริ่มต้นต่ำ ทำให้ไม่สามารถควบคุมการเคลื่อนไหวแบบละเอียด (เช่น เล็งเป้าแบบละเอียดยิบหรือแก้ไขเป้าเล็ก ๆ) ได้ดีนัก

ปัญหาที่พบ:

- ล้อมี Deadzone ขนาดใหญ่: PWM ต่ำกว่า ~145 ไม่สามารถทำให้ล้อเริ่มหมุนได้ ต้องใช้แรงกระตุ้นสูงมากขึ้น
- เกิดการ “กระชาก” เมื่อล้อเริ่มหมุน: เนื่องจากแรงบิดต่ำ พอเพิ่ม PWM จนพ้น Deadzone ล้อจะหมุนเร็วเกิน ทำให้เคลื่อนไหวไม่ละเอียดพอ
- มีผลโดยตรงต่อการจูน PID: ค่าความเร็วเริ่มต้นที่ไม่ต่อเนื่องทำให้หาค่า Kp, Kd ที่สมดุลได้ยากในความเร็วต่ำ

ข้อเสนอแนะสำหรับรุ่นถัดไป:

- อาจพิจารณาเปลี่ยนเป็นมอเตอร์ที่มี อัตราทดสูงขึ้น (เช่น 1:100) หรือ มอเตอร์แบบมี Encoder เพื่อให้สามารถควบคุมความเร็วและตำแหน่งได้แม่นยำขึ้น
- อีกทางเลือกคือการใช้ มอเตอร์แบบ Stepper หรือ Servo ซึ่งให้ความละเอียดและ Feedback ที่เหมาะกับงานประเภท Precision Control

# บทที่ 3 ระเบียบวิธีวิจัย

## 3.1 ภาพรวมของระบบ (System Overview)

โครงสร้างภาพรวมของระบบนี้แบ่งออกเป็นหลายโมดูลที่ทำงานร่วมกันเพื่อให้ได้ระบบ Physical Aimbot ที่สามารถจับภาพจาก Kovaak, ประมวลผลข้อมูลด้วยโมเดล YOLO, คำนวณ Inverse Kinematics และควบคุมการเคลื่อนที่ของหุ่นยนต์ พร้อมทั้งส่งคำสั่งคลิกกลับไปยัง PC ผ่าน ESP32

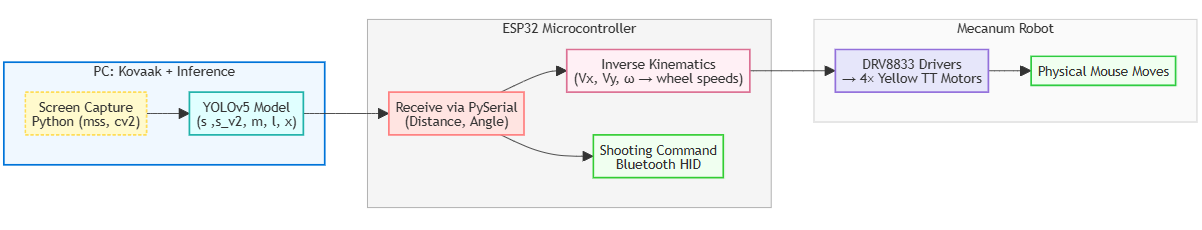
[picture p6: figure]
รูปภาพประกอบด้วย ข้อความ, ตัวอักษร, ไลน์, ภาพหน้าจอ เนื้อหาที่สร้างโดย AI อาจไม่ถูกต้อง

ส่วนประกอบหลักของระบบมีดังนี้:

1. Screen Capture Module:
  - โปรแกรม Python ใช้จับภาพหน้าจอจากโปรแกรม Kovaak
  - ภาพที่จับได้ถูกส่งต่อไปยังโมเดล YOLO เพื่อทำการตรวจจับวัตถุ
2. Object Detection Module (YOLO Model):
  - โมเดล YOLO (เช่น YOLOv5s หรือ YOLOv5m ตามที่เลือก) ประมวลผลภาพที่ได้รับจาก Screen Capture
  - ตรวจจับตำแหน่งเป้าหมาย (bounding boxes, confidence scores) และส่งข้อมูลผลลัพธ์ไปยัง ESP32
3. ESP32 Microcontroller:
  - รับข้อมูลจากโมเดล YOLO ผ่านการสื่อสาร (PySerial)
  - คำนวณ Inverse Kinematics (หรือรับค่าที่คำนวณจาก PC ขึ้นอยู่กับประสิทธิภาพ) เพื่อแปลงข้อมูลตำแหน่งเป้าหมายเป็นคำสั่งสำหรับควบคุมมอเตอร์ (เช่น ค่าความเร็วและมุมของแต่ละล้อ)
  - สั่งการเคลื่อนที่ของหุ่นยนต์ตามข้อมูลที่คำนวณได้
  - ส่งคำสั่งการคลิก (Shooting Command) ผ่าน Bluetooth กลับไปยัง PC เมื่อเป้าหมายอยู่ในขอบเขตที่กำหนด
4. Motor Control Module:
  - มอเตอร์ (Yellow TT Motor) ที่ติดตั้งกับล้อ Mecanum รับคำสั่งจาก ESP32 เพื่อขับเคลื่อนหุ่นยนต์ให้เคลื่อนที่ไปตามตำแหน่งที่ต้องการ
5. Communication Flow:
  - PC: จับภาพหน้าจอจาก Kovaak → ส่งข้อมูลไปยังโมเดล YOLO
  - Model: ตรวจจับเป้าหมาย → ส่งผลลัพธ์ (ตำแหน่งเป้าหมาย) ไปยัง ESP32
  - ESP32: คำนวณ Inverse Kinematics → สั่งมอเตอร์เคลื่อนที่ → ส่งคำสั่งคลิกกลับไปยัง PC

หมายเหตุ: โครงสร้างระบบดังแสดงนี้เป็นแนวทางเริ่มต้นที่ออกแบบไว้ อย่างไรก็ตาม จากการทดลองจริงพบข้อจำกัดในเรื่องเวลาและความยืดหยุ่นของระบบ จึงมีการปรับให้ฝั่ง PC รับหน้าที่คำนวณ Inverse Kinematics และจำลองคลิกทั้งหมดแทนการใช้ ESP32 เพื่อเพิ่มความสะดวกและลดเวลาในการพัฒนา รายละเอียดการปรับเปลี่ยนดังกล่าวจะอธิบายเพิ่มเติมในบทถัดไป

## 3.2 วิธีการบันทึกวิดีโอการเล่นโปรแกรม Kovaak

### 3.2.1 วิธีการบันทึกวิดีโอการเล่นโปรแกรม Kovaak

ในการสร้าง Dataset สำหรับตรวจจับเป้าหมาย (Targets) ในโปรแกรม Aim Training อย่าง Kovaak ผู้วิจัยได้ทำการบันทึกวิดีโอของการเล่นทั้งหมด 5 ฉาก (Scenarios) ซึ่งประกอบด้วย:

1. 3D Switching Robots
2. Buff Robots 360
3. Close Fast Strafes Easy Invincible Robot 25% Slower
4. CLS Click Robots Rounded
5. Correction Accuracy – Close I Strafe Robot
- ระยะเวลา: แต่ละฉากมีความยาวประมาณ 1 นาที รวมเป็นเวลาทั้งสิ้นประมาณ 5 นาที
- ความละเอียด (Resolution): 1920 × 1080
- อัตราเฟรม (Frame Rate): 30 FPS

โดยใช้โปรแกรมบันทึกวิดีโอหน้าจอ (Screen Recording) ในสภาพแวดล้อมการเล่นปกติของ Kovaak เพื่อให้ได้ข้อมูลการเล็งเป้าหมายที่ใกล้เคียงการใช้งานจริงที่สุด

### 3.2.1 การดึงภาพจากวิดีโอด้วย OpenCV และขั้นตอนการ Label ข้อมูลเป้าหมาย (Object Labeling)

หลังจากได้ไฟล์วิดีโอทั้ง 5 ฉากแล้ว ผู้วิจัยจึงนำวิดีโอเหล่านั้นมาประมวลผลด้วย Python และ OpenCV เพื่อแยกเฟรมออกมาเป็นรูปภาพ (.png) ดังตัวอย่างโค้ดด้านล่าง (extract_frame.py):

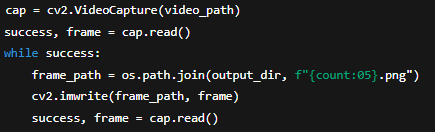
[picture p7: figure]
รูปภาพประกอบด้วย ข้อความ, ภาพหน้าจอ, ตัวอักษร เนื้อหาที่สร้างโดย AI อาจไม่ถูกต้อง

1. กระบวนการดึงภาพ (Frame Extraction):
  - โปรแกรมจะเปิดวิดีโอแต่ละไฟล์และอ่านเฟรมทีละเฟรม
  - แต่ละเฟรมจะถูกบันทึกเป็นไฟล์ภาพ .png ไว้ในโฟลเดอร์แยกตามชื่อวิดีโอ
  - ทำให้ได้จำนวนภาพทั้งหมดหลายพันภาพ (ขึ้นอยู่กับความยาววิดีโอและอัตราเฟรม)
2. การ Label ข้อมูล (Object Labeling):
  - นำภาพที่ได้ไปทำ Label จุด (Bounding Box) ของ “Robot” ซึ่งเป็นเป้าหมายหลักในการฝึกเล็ง
  - รูปแบบการบันทึก Label เป็น YOLO v5 PyTorch format เพื่อให้สอดคล้องกับโมเดล YOLO ที่จะใช้งานต่อไป
  - ใช้เครื่องมือออนไลน์ (เช่น Roboflow หรือโปรแกรม Labeling อื่น ๆ) เพื่อช่วยในการ Annotate วัตถุ

### 3.2.3 การทำ Augmentation ผ่าน Roboflow

หลังจากได้ภาพที่ Label เสร็จเรียบร้อย ผู้วิจัยได้ทำ Data Augmentation โดยใช้แพลตฟอร์ม Roboflow เพื่อเพิ่มความหลากหลายของภาพและลดปัญหา Overfitting ซึ่งรายละเอียดของการ Augment มีดังนี้:

1. จำนวน Dataset:
  - Dataset มีภาพทั้งหมดประมาณ 11,342 ภาพ (รวมภาพต้นฉบับและภาพที่ผ่านการ Augmentation)
2. การปรับขนาด (Resize):
  - แต่ละภาพถูกปรับขนาดเป็น 640 × 640 (Stretch) เพื่อให้ตรงกับ input size ของ YOLOv5
3. การ Flip และ Crop:
  - Horizontal Flip (50% Probability) ช่วยจำลองตำแหน่งของศัตรูที่อาจโผล่มาทั้งด้านซ้ายและขวาในฉากเกม เพื่อให้โมเดลไม่ Bias ด้านใดด้านหนึ่ง
  - Vertical Flip (50% Probability) ช่วยจำลองตำแหน่งของศัตรูที่อาจโผล่มาทั้งด้านซ้ายและขวาในฉากเกม เพื่อให้โมเดลไม่ Bias ด้านใดด้านหนึ่ง
  - Random Crop ระหว่าง 0% ถึง 20% ของ Bounding Box ช่วยให้โมเดลเรียนรู้จากสถานการณ์ที่เป้าหมายบางส่วนอาจถูกซ่อนอยู่หลังวัตถุหรือขอบจอ เช่น เป้าหมายหลบอยู่หลังของฉากในเกม
4. การ Shear (บิดภาพ):
  - มีการสุ่มค่าการ Shear ในช่วง -10° ถึง +10° ทั้งแนวนอนและแนวตั้ง ใช้เพื่อจำลองความเบลอหรือ distortion จากการเคลื่อนที่เร็วในเกม (เช่นตอนเป้าหมาย strafe อย่างรวดเร็ว)
5. Auto-Orientation และ EXIF Stripping:
  - มีการปรับ Orientation ของภาพอัตโนมัติเพื่อให้ทิศทางของภาพถูกต้องเสมอ
  - ลบข้อมูล EXIF ที่ไม่จำเป็นออก

การ Augmentation ดังกล่าวช่วยเพิ่มความหลากหลายของภาพและสถานการณ์การเล็งเป้า ทำให้โมเดลเรียนรู้ได้ครอบคลุมมากขึ้น อย่างไรก็ตาม นี่เป็นการตั้งค่าพื้นฐานในการ Augment ครั้งแรกเท่านั้น ซึ่งวางแผนที่จะปรับปรุงหรือเปลี่ยนแปลงพารามิเตอร์ในอนาคต เมื่อมีการปรับแต่งระบบหุ่นยนต์และโมเดล YOLO ให้มีประสิทธิภาพมากขึ้น

### 3.2.4 การสร้าง Dataset v2 (Scenarios ขยาย + Quality Control)

เนื่องจาก Dataset ชุดแรก มีปริมาณภาพค่อนข้างน้อย และครอบคลุมเพียง 5 Scenarios ที่มีลักษณะคล้ายกัน เช่น robot เดินตรงใน map เดิม ทำให้โมเดลที่ฝึกจากข้อมูลดังกล่าวมีแนวโน้ม overfit และ ขาดความสามารถในการ generalize เมื่อนำไปใช้กับฉากใหม่ ๆ ที่มีลักษณะแตกต่างกัน เช่น robot ซ้อนกันหลายตัว / แสงต่างกัน / map คนละแบบ
นอกจากนี้ในเวอร์ชันแรกมีการ label อย่างเร่งรีบ จึงอาจเกิด miss-label และ noise ในชุดข้อมูล ได้สูง

ผู้วิจัยจึงตัดสินใจสร้าง Dataset v2 โดยปรับปรุงทั้งด้าน ปริมาณ, คุณภาพ, และ ความหลากหลายของสถานการณ์

Scenarios ใหม่ที่เพิ่ม:
เพิ่ม 10 ฉากใหม่ที่ครอบคลุมลักษณะการเล่นที่หลากหลาย เช่น tracking, click-timing, low-ground jumps, long-range flicks เพื่อให้ Dataset มีความหลากหลายและครอบคลุมสถานการณ์จริงมากขึ้น

การดึงเฟรม:
ลด sampling เป็น 5 fps (เลือกทุก 6 เฟรมจากวิดีโอ 30 fps ความยาว 1 นาที) เพื่อหลีกเลี่ยงข้อมูลซ้ำซ้อนเกินไป และยังช่วยให้สามารถเพิ่มจำนวน scenario ได้มากขึ้นภายใต้จำนวนเท่าเดิม

จำนวนภาพหลัง extraction:
ได้ภาพทั้งหมด 38,409 ภาพ ซึ่งมากกว่าชุดก่อนหน้าถึง 3.4 เท่า

การตรวจสอบ label:
มีการตรวจสอบ bounding box เดิมอย่างละเอียด และแก้ไข miss-label ที่พบก่อนจะทำการ export เป็น YOLO v5 (PyTorch format) เพื่อเตรียมใช้ในการฝึกโมเดลจริง

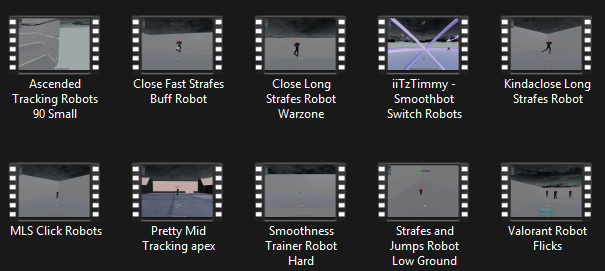
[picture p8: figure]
รูปภาพประกอบด้วย ข้อความ, ภาพหน้าจอ, ซอฟต์แวร์มัลติมีเดีย, วงจรไฟฟ้า เนื้อหาที่สร้างโดย AI อาจไม่ถูกต้อง

ภาพ Dataset ชุดใหม่ที่เพิ่มขึ้น

### 3.2.4.1 Pre-processing

- Auto-orientation & EXIF strip – ป้องกันปัญหารูปกลับหัวเวลาภาพมาจากเครื่องต่างแพลตฟอร์ม
- Adaptive equalization – เพิ่ม contrast ใน map ที่มี fog หรือ low-light (เช่นฉาก Valorant Robot Flicks)
- Resize 640 × 640 (Stretch) – ตรงตามค่า --img 640 ของโมเดลทุกขนาด

### 3.2.4.2 Augmentation (7× per source)

มีการใช้เทคนิค Augmentation หลากหลายรูปแบบเพื่อจำลองสถานการณ์ต่าง ๆ ที่เกิดขึ้นจริงในเกม โดยมีรายละเอียดดังนี้:

- Horizontal Flip (50%) เพื่อจำลองการเคลื่อนไหวของเป้าหมายที่ strafe ซ้าย/ขวาสลับไปมาอย่างต่อเนื่องในเกม FPS ซึ่งเป็นหนึ่งในสถานการณ์ที่พบได้บ่อย
- Random Rotation (±15°) ใช้เพื่อเลียนแบบการส่ายกล้องเร็ว หรือการเคลื่อนไหวแบบ flick ของผู้เล่นที่หมุนเล็งเป้าแบบฉับพลัน
- Brightness Adjustment (–20% ถึง +20%) และ Exposure (±10%) จำลองการเปลี่ยนแปลงของแสงใน Arena หรือแผนที่ ซึ่งเกิดขึ้นได้เมื่อกล้องหมุนผ่านจุดที่มีความสว่างต่างกัน เช่น โซนแสงแดดและโซนเงา
- Box Crop (0–20%) เพื่อจำลองสถานการณ์ที่เป้าหมายโผล่แค่ครึ่งตัว เช่น เมื่อยืนหลังกำแพง สิ่งกีดขวาง หรือโผล่จากมุมบัง
- Shear (±10°), Gaussian Blur (0–0.1px), และ Salt-Pepper Noise (0.06%) ใช้จำลอง motion blur และ noise ที่เกิดขึ้นจริงเมื่อมีการเคลื่อนไหวเร็ว เช่น การวิ่งหรือเป้าหมายหมุนตัว

## 3.3 การฝึกและประเมินผลโมเดล YOLO (Model Training and Evaluation)

### 3.3.1 สภาพแวดล้อมที่ใช้ในการฝึกโมเดล (Hardware Spec, Software Environment, Libraries)

- ฮาร์ดแวร์ (Hardware):
  - ใช้เครื่อง ASUS TUF A15 Laptop ที่มาพร้อมกับ RTX 3060
  - CPU: Ryzen 7 6700H
  - RAM: 16GB DDR5 (ความถี่ 4800Hz)
  - SSD สำหรับความเร็วในการอ่านเขียนข้อมูล
- สภาพแวดล้อมการฝึก (Training Environment):
  - ใช้ Conda Environment สำหรับการติดตั้ง Python libraries ที่เกี่ยวข้องกับ YOLOv5
  - Libraries ที่สำคัญ: PyTorch, OpenCV, NumPy, และอื่น ๆ ตามที่ระบุใน requirements.txt ของ YOLOv5

### 3.3.1.1 การย้ายและปรับปรุงสภาพแวดล้อมการฝึกโมเดล

หลังจากการฝึกโมเดลรอบแรกเสร็จสิ้น ผู้วิจัยพบว่าเครื่องคอมพิวเตอร์ส่วนตัวที่ใช้ในการฝึก (ASUS TUF A15, GPU: RTX 3060) เริ่มมีข้อจำกัดด้านเวลาและประสิทธิภาพเมื่อใช้กับ Dataset ที่มีขนาดใหญ่ขึ้น (Dataset v2)

เมื่อเริ่มทดลองเทรนโมเดลขนาดกลาง (YOLOv5m) พบปัญหาหลายประการ ได้แก่:

- ระยะเวลาในการฝึก 1 epoch ใช้นานมาก (ประมาณ 60 นาทีต่อ epoch)
- เทรนยังไม่ทันครบรอบเกิด error ด้านหน่วยความจำ เช่น out of memory / CUDA crash
- ไม่สามารถเพิ่ม batch size ได้เกิน 12 โดยไม่เกิดปัญหา

ด้วยเหตุนี้ ผู้วิจัยจึงตัดสินใจ ย้ายการฝึกทั้งหมดไปที่เซิร์ฟเวอร์ของคณะ ที่มีทรัพยากรสูงกว่าอย่างชัดเจน โดยมีสเปคดังนี้:

การใช้งาน GPU และระบบ Remote:
ระบบใช้ GPU แบบ Dual Tesla V100 (หน่วยละ 32 GB VRAM) โดยใช้งานผ่านการ เชื่อมต่อระยะไกล (Remote) ด้วย SSH ทั้งหมด เพื่อประมวลผลและฝึกโมเดล

สามารถ ฝึกโมเดลได้พร้อมกัน 2 โมเดล โดยแยกการใช้งาน GPU ออกจากกันชัดเจน

- โมเดลที่ 1 ใช้งานด้วยคำสั่ง --device 0
- โมเดลที่ 2 ใช้งานด้วยคำสั่ง --device 1

เพื่อหลีกเลี่ยงการชนกันของ Cuda core และใช้ทรัพยากรอย่างมีประสิทธิภาพสูงสุด

ทำให้สามารถเพิ่ม batch size ได้มากขึ้น, ใช้เวลาน้อยลงกว่าเดิมหลายเท่า และลดความเสี่ยงเรื่องเทรนไม่จบหรือเครื่องค้าง

### 3.3.2 ขั้นตอนการ Train โมเดล YOLOv5 (เวอร์ชัน Small) และการตั้งค่าพารามิเตอร์ (Hyperparameter Tuning)

### 3.3.2.1 การฝึก YOLOv5s รุ่นแรก (Training V1 – Dataset v1)

- การเตรียมข้อมูล:
  - ใช้ Dataset ที่ได้จากขั้นตอน 3.2 ซึ่งประกอบด้วยภาพที่ Label แล้วในรูปแบบ YOLO v5 PyTorch format
- คำสั่งการฝึก (Training Command): ใช้คำสั่งต่อไปนี้เพื่อฝึกโมเดล YOLOv5s:

python train.py --img 640 --batch 16 --epochs 100 --data "D:/UNIVERSITY/YR3/FRA361_Open_Topic/DATASET/For Train/FRA361_OpenTopic_Aimbot.v1i.yolov5pytorch/data.yaml" --cfg models/yolov5s.yaml --weights yolov5s.pt --device 0 --optimizer Adam --noautoanchor --sync-bn

  - อธิบาย Parameter:
    - --img 640: ปรับขนาดภาพเป็น 640×640
    - --batch 16: ใช้ batch size 16
    - --epochs 100: ฝึกโมเดลเป็นเวลา 100 epochs
    - --data .../data.yaml: ระบุไฟล์ข้อมูล Dataset
    - --cfg models/yolov5s.yaml: กำหนด configuration ของ YOLOv5s
    - --weights yolov5s.pt: เริ่มต้นด้วย pre-trained weights ของ YOLOv5s
    - --device 0: ใช้ GPU ที่มี ID 0
    - --optimizer Adam: ใช้ออปติไมเซอร์ Adam
    - --noautoanchor: ปิดการสร้าง anchor โดยอัตโนมัติ
    - --sync-bn: ใช้ synchronized Batch Normalization สำหรับการฝึกบน GPU หลายตัว (ถ้ามี)
- การปรับพารามิเตอร์:
  - ในขั้นตอนแรกจะเริ่มฝึกด้วย YOLOv5s (Small)
  - เนื่องจาก PC ของเรามีประสิทธิภาพสูง (สามารถรันได้ 200+ FPS) จึงมีความเป็นไปได้ที่จะลองปรับเป็น YOLOv5m (Medium) ในอนาคตเพื่อเพิ่มความแม่นยำ

3.3.2.2 การฝึก YOLOv5s_v2 / m / l / x บน Dataset v2 (Training V2)

หลังปรับ Dataset (หัวข้อ 3.2.4) ให้ใหญ่และหลากหลายขึ้น ผู้วิจัยใช้ทรัพยากร V100 2 ตัว เทรนโมเดล 4 ขนาด

Model | Device (GPU) | Batch | Epochs (early-stop) | พารามิเตอร์ | Command key-points
yolov5s_v2 | --device 1 (V100-#2) | 32 | 150 → หยุดที่ 109 | 7.0 M params, 15.8 GFLOPs | train from scratch (เนื่องจาก weight ที่จะใช้เทรนด์ใน window แต่ต้องย้ายมาใช้ใน Linux ทำให้เกิดความขัดแย้งกัน)
yolov5m | --device 0 (V100-#1) | 24 | 200 → หยุดที่ 112 | 20.9 M params, 47.9 GFLOPs
yolov5l | --device 0 | 16 | 200 → หยุดที่ 58 | 46.1 M params, 107 GFLOPs
yolov5x | --device 1 | 12 | 200 → หยุดที่ 59 | 87 M params, 218 GFLOPs

Option ร่วมที่เปิดทุกโมเดล

--optimizer Adam # learning-rate ยืดหยุ่น

--sync-bn # batch norm ข้าม GPU

--rect # rectangular training ลด VRAM + เพิ่ม IoU

--patience 50 # early stop ถ้า val-mAP ไม่ดีขึ้น

เหตุผลเพิ่ม L และ X – เมื่อมี VRAM/เวลาเหลือจึงขยายการทดลอง เพื่อดูว่าความแม่นยำจะคุ้มค่า latency หรือไม่ในงาน real-time

### 3.3.3 การประเมินผลโมเดล (Evaluation Metrics)

### 3.3.3.1 ผลลัพธ์ YOLOv5s รุ่นแรก (Training V1)

- ตัวชี้วัดหลักที่ใช้วัดผล:
  - Precision: วัดความแม่นยำของการตรวจจับ (จำนวนการตรวจจับที่ถูกต้องต่อการตรวจจับทั้งหมด)
  - Recall: วัดความสามารถในการจับเป้าหมายที่มีอยู่จริง
  - mAP (mean Average Precision): ประเมินความแม่นยำเฉลี่ยของโมเดลในการตรวจจับวัตถุ
  - Confidence Score: คะแนนความมั่นใจของโมเดลในการตรวจจับแต่ละกล่อง
- ผลการประเมินจาก YOLOv5s (Final Evaluation Results):

จากผลลัพธ์การประเมินขั้นสุดท้ายของ YOLOv5s บนชุดทดสอบ (Validation Set) ได้ค่าชี้วัดดังนี้:

  - Precision: 0.932
  - Recall: 0.804
  - mAP (mean Average Precision): 0.892
  - Confidence Score: 0.504
- ซึ่งค่าดังกล่าวแสดงให้เห็นว่าโมเดลมีความสามารถในการตรวจจับเป้าหมายในระดับที่น่าพอใจ โดยมีความแม่นยำในการจับวัตถุสูง และสามารถจับได้ในหลายสถานการณ์ที่หลากหลาย โดยเฉพาะ mAP@0.5 ที่เกิน 0.85 ถือว่ามีความแม่นยำที่เหมาะสมสำหรับงานเบื้องต้น
  - อย่างไรก็ตาม ค่า mAP@0.5:0.95 ยังมีพื้นที่ให้ปรับปรุง ซึ่งเป็นสิ่งที่คาดการณ์ไว้แล้วจากลักษณะของ Dataset ที่มีการ Label ผิดพลาดบางส่วน และการ Augment ที่อาจยังไม่ครอบคลุมความหลากหลายของ Scenarios ทั้งหมด
- ผลลัพธ์ที่สังเกตได้:

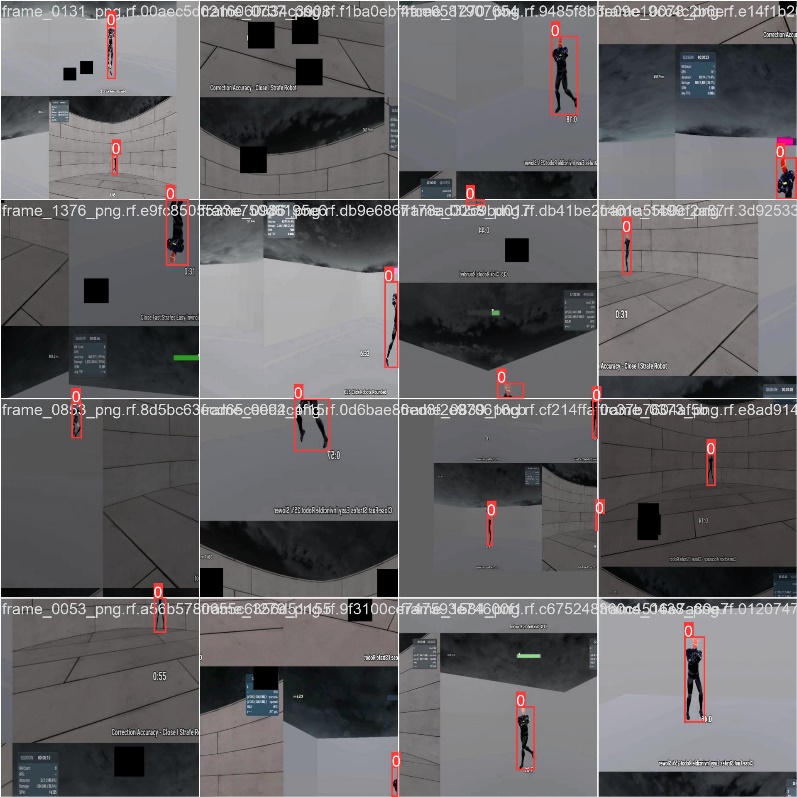
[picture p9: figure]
รูปภาพประกอบด้วย ภาพหน้าจอ, ข้อความ, โมเสก เนื้อหาที่สร้างโดย AI อาจไม่ถูกต้อง

  - จากผลการฝึกเบื้องต้น พบว่าโมเดลสามารถตรวจจับเป้าหมายในบางสถานการณ์ได้อย่างแม่นยำและไม่เกิดการตรวจจับผิด (False Positives)
  - ในบางฉากที่มีความซับซ้อนหรือมีความเคลื่อนไหวรวดเร็ว โมเดลอาจพลาดเป้าหมาย (Missed Detections)
  - ผลลัพธ์ที่แสดงในภาพตัวอย่าง (เช่น train result.png, train_batch2.jpg) แสดงให้เห็นถึงการทำงานที่ดีในบางสถานการณ์ แต่ยังมีพื้นที่ให้ปรับปรุงความแม่นยำและความเสถียรในสถานการณ์ที่ท้าทาย
- แผนการปรับปรุง:
  - ปรับปรุง Dataset โดยตรวจสอบและเพิ่มจำนวนภาพในสถานการณ์ที่โมเดลพลาดเป้าหมาย
  - Fine-tune พารามิเตอร์การฝึกและพิจารณาการเปลี่ยนแปลงจาก YOLOv5s เป็น YOLOv5m เมื่อการผสานระบบฮาร์ดแวร์เสร็จสมบูรณ์

### 3.3.3.2 ผลลัพธ์ Training V2 (Dataset v2)

Metric | s_v2 | m | l | x
Precision | 0.885 | 0.843 | 0.821 | 0.844
Recall | 0.652 | 0.602 | 0.681 | 0.681
mAP@0.5 | 0.789 | 0.747 | 0.761 | 0.770
mAP@0.5:0.95 | 0.381 | 0.313 | 0.256 | 0.290
Inference (ms) @640 | 2.0 | 4.7 | 8.2 | 14.6

จากผลการฝึกและการประเมินโมเดล YOLOv5 ทั้ง 4 ขนาด (s_v2, m, l, x) บน Dataset v2 สามารถสรุปข้อสังเกตได้ดังนี้:

- YOLOv5s_v2 แสดงประสิทธิภาพโดยรวมดีที่สุดเมื่อพิจารณาทั้งด้าน ความแม่นยำ (Accuracy) และ ความเร็วในการประมวลผล (Latency)
  - mAP@0.5: 0.789
  - Latency: 2.0 ms/frame เหมาะอย่างยิ่งสำหรับระบบที่ต้องการทำงานแบบเรียลไทม์ (real-time)
- YOLOv5m แม้มีจำนวนพารามิเตอร์มากกว่า แต่พบว่า Recall ลดลง และมีแนวโน้มที่จะเกิด Overfitting
  - mAP@0.5: 0.747
  - Recall: 0.602
  - Latency: 4.7 ms/frame
- YOLOv5l มี Recall สูงสุด ในบรรดาทั้งหมด
  - Recall: 0.681
  - mAP@0.5: 0.761
  - Latency: 8.2 ms/frame เริ่มมีผลต่อความลื่นไหลของเกมในระบบที่มีข้อจำกัดด้านประสิทธิภาพ
- YOLOv5x ให้ค่าความแม่นยำสูงใกล้เคียง s_v2 แต่มี latency สูงสุด
  - mAP@0.5: 0.770
  - Latency: 14.6 ms/frame ซึ่งอาจทำให้ระบบมี FPS ต่ำกว่าที่สามารถใช้งานได้จริงในเกมแนว FPS

### 3.3.4 ปัญหา & แนวทางแก้ไข

สำหรับการฝึกโมเดลรอบใหม่ (Training V2) ผู้วิจัยพบปัญหาเพิ่มเติมที่ไม่เคยเกิดขึ้นในรอบแรก โดยได้ดำเนินการวิเคราะห์และวางแนวทางในการแก้ไขไว้ดังนี้:

### 3.3.4.1 ปัญหาในการใช้งาน Weight ระหว่าง Windows และ Linux

ปัญหา:
เดิมผู้วิจัยมีแผนที่จะนำ weight จาก Windows ที่ฝึกไว้ก่อนหน้านี้มาใช้ต่อบนระบบ Linux ที่ใช้เซิร์ฟเวอร์คณะฯ (Tesla V100 ×2) แต่ขณะนั้นมีการฝึกโมเดลอีกตัวหนึ่งอยู่พร้อมกันบนอีก GPU และการจะฝึก “ต่อ” (continue training) จำเป็นต้องแก้ไขไฟล์ train.py ซึ่งมีความเสี่ยงสูงที่จะกระทบกับกระบวนการฝึกของอีกโมเดลที่กำลังทำงานอยู่

ด้วยข้อจำกัดดังกล่าว ผู้วิจัยจึงตัดสินใจเริ่มฝึก YOLOv5s_v2 ใหม่ทั้งหมด โดยใช้ pretrained weights พื้นฐาน (yolov5s.pt) แทนที่จะโหลด weights ที่เทรนไว้ก่อนหน้า

หลังจากนั้น เมื่อจะนำ weight ที่ฝึกเสร็จแล้วบนระบบ Linux มาใช้งานจริงบนเครื่อง PC (Windows) พบปัญหาเพิ่มเติม คือ torch.load() ไม่สามารถโหลด path ที่เซฟไว้ในรูปแบบ PosixPath ได้ในระบบ Windows ส่งผลให้เกิดข้อผิดพลาด KeyError: model.ema หรือ AttributeError: PosixPath object has no attribute 'read'

แนวทางแก้ไข:
เพื่อให้สามารถใช้งาน weight ได้บน Windows จำเป็นต้องเพิ่มคำสั่ง patch ที่หัวไฟล์ Python ก่อนเรียก torch.load() ดังนี้:

import pathlib

pathlib.PosixPath = pathlib.WindowsPath

คำสั่งนี้จะช่วยให้ระบบ Windows สามารถแปลงและอ่าน path ที่บันทึกมาจากระบบ Linux ได้อย่างถูกต้อง

### 3.3.4.2 ปัญหา VRAM Overflow บน RTX 3060

ปัญหา:
ในการฝึกโมเดลขนาดกลาง (YOLOv5m) โดยใช้ Dataset v2 ที่มีจำนวนภาพเพิ่มขึ้น พบว่าเมื่อใช้ batch size มากกว่า 12 จะเกิดปัญหา CUDA out-of-memory (OOM) บนเครื่องที่ใช้ GPU RTX 3060

แนวทางแก้ไข:
ผู้วิจัยจึงตัดสินใจย้ายการฝึกทั้งหมดไปยังเซิร์ฟเวอร์คณะฯ ที่มี GPU Tesla V100 จำนวน 2 ตัว ซึ่งสามารถรองรับการฝึกโมเดลขนาดใหญ่ได้ดี และยังสามารถเปิด option --rect เพื่อช่วยลด memory footprint ในการจัด batch ขณะฝึกได้อีกด้วย

## 3.4 การออกแบบและพัฒนาฮาร์ดแวร์ (Hardware Design and Development)]

### 3.4.1 รายละเอียดการออกแบบ CAD

- เครื่องมือ:
  - ใช้โปรแกรม SolidWorks ในการออกแบบโครงสร้างหุ่นยนต์
- มุมมองการออกแบบ:
  - มีการสร้างภาพจากมุมต่าง ๆ
  - Front View
  - Top View
  - Side View
  - Isometric View

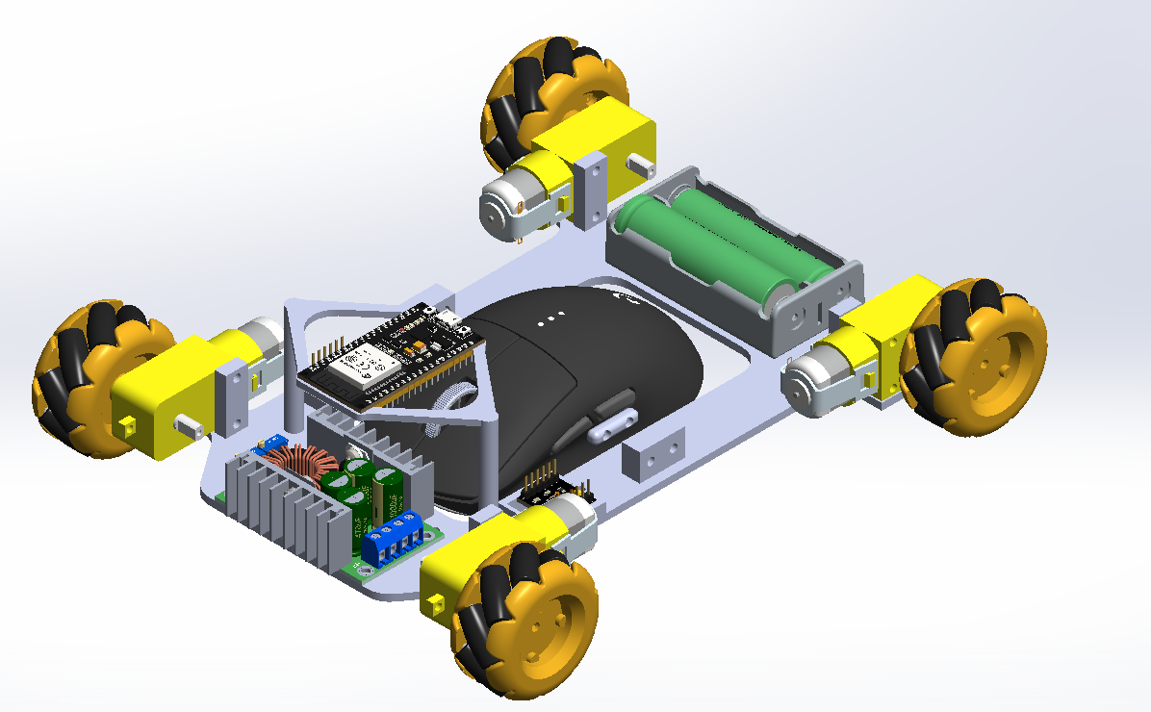
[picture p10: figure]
รูปภาพประกอบด้วย ของเล่น, ล้อ, ของเล่นรถ, อะไหล่รถยนต์ เนื้อหาที่สร้างโดย AI อาจไม่ถูกต้อง

- รายละเอียด:
  - การออกแบบ CAD แสดงตำแหน่งของอุปกรณ์หลัก เช่น มอเตอร์, ล้อ Mecanum, ESP32, แบตเตอรี่, และส่วนประกอบ 3D Printed
  - โดยมีการวางแผนระบบสองชั้น (First floor สำหรับการประกอบฮาร์ดแวร์หลัก และ Second floor สำหรับการติดตั้ง ESP32 เพื่อการจัดการสายไฟที่ดีขึ้น)

### 3.4.2 รายการอุปกรณ์ที่ใช้ (Bill of Materials - BOM)

รายการอุปกรณ์หลักที่ใช้ในโครงงานนี้มีดังนี้:

- แบตเตอรี่และอุปกรณ์จัดเก็บพลังงาน:
  - 1 × 2 Battery 18650 Rail: ที่ใช้สำหรับติดตั้งแบตเตอรี่ 18650
  - 2 × 18650 Batteries: แบตเตอรี่ลิเธียมชนิดชาร์จได้ สำหรับจ่ายพลังงานให้กับระบบ (เลือกใช้รุ่นนี้เนื่องจากมีเครื่องชาร์จสำหรับแบตเตอรี่ประเภทนี้อยู่แล้ว)
- ล้อและการเคลื่อนที่:
  - 4 × Mecanum Wheels (48mm): แบ่งเป็น 2 ล้อซ้ายและ 2 ล้อขวา สำหรับให้ความสามารถในการเคลื่อนที่แบบ omnidirectional
- อุปกรณ์เสริม:
  - Logitech G Pro X Superlight Mouse: ใช้เป็นตัวทดสอบการควบคุมการเล็ง
- ไมโครคอนโทรลเลอร์และการสื่อสาร:
  - ESP32 38-pin: สำหรับการประมวลผลและสื่อสารข้อมูล (ทั้งผ่าน WiFi และ Bluetooth)
  - Top ESP32 Mount (3D Printed): ชุดที่ติดตั้งบนชั้นบนของระบบ เพื่อจัดการสายไฟและการเชื่อมต่อที่สะดวก
- การควบคุมแรงดันไฟฟ้า:
  - XL4016E1 Step Down Converter: ใช้ปรับแรงดันจากแบตเตอรี่ให้เหมาะสมกับระบบ
- มอเตอร์และไดรเวอร์:
  - 4 × Yellow TT Motors (Gear Ratio 1:48): มอเตอร์ที่เลือกใช้เพื่อให้ได้ความเร็วในการเคลื่อนที่ที่สูงขึ้น (แม้แรงบิดจะต่ำกว่า แต่เพียงพอสำหรับระบบเมาส์ที่เบา)
  - 2 × DRV8833 Motor Drivers: ใช้ควบคุมมอเตอร์ 4 ตัว (แต่ละไดรเวอร์ควบคุมมอเตอร์ 2 ตัว) เนื่องจากมีขนาดเล็ก น้ำหนักเบา และเหมาะสำหรับการใช้งานในระบบนี้
- ส่วนประกอบ 3D Printed:
  - 1 Base: โครงสร้างหลักที่ถูกพิมพ์ 3D เพื่อรองรับการติดตั้งอุปกรณ์ทั้งหมด
  - 2 × Mouse Lock (3D Printed): ชิ้นส่วนที่ช่วยยึดตำแหน่งเมาส์ให้คงที่ในขณะใช้งาน

### 3.4.3 กระบวนการประกอบชิ้นส่วนจริงตามแบบ CAD

ในการประกอบชิ้นส่วนจริงจากแบบ CAD ผู้วิจัยได้ดำเนินการตามขั้นตอนที่ออกแบบไว้ แต่พบปัญหาบางประการที่สำคัญในการประกอบครั้งแรก ดังนี้:

1. ปัญหาด้านการพิมพ์ 3D (วัสดุ PETG)
เนื่องจากเป็นครั้งแรกที่เครื่องพิมพ์ 3D ของผู้วิจัยใช้งานวัสดุ PETG ทำให้การตั้งค่าเครื่องพิมพ์ยังไม่เหมาะสม และเซ็นเซอร์ของเครื่องพิมพ์มีปัญหา ส่งผลให้ชิ้นงานที่พิมพ์ออกมามีความแข็งแรงต่ำ มีลักษณะเปราะ หรืออ่อนตัวมากจนคล้ายสปริง ชิ้นงานบางชิ้นเกิดการบิดโค้ง ไม่ตรงตามที่ออกแบบไว้ ส่งผลให้เมื่อประกอบแล้วตัวหุ่นยนต์มีลักษณะโยกเยก ไม่มั่นคง

- ภาพแสดงชิ้นส่วนที่มีปัญหาการพิมพ์ (ครั้งแรก)

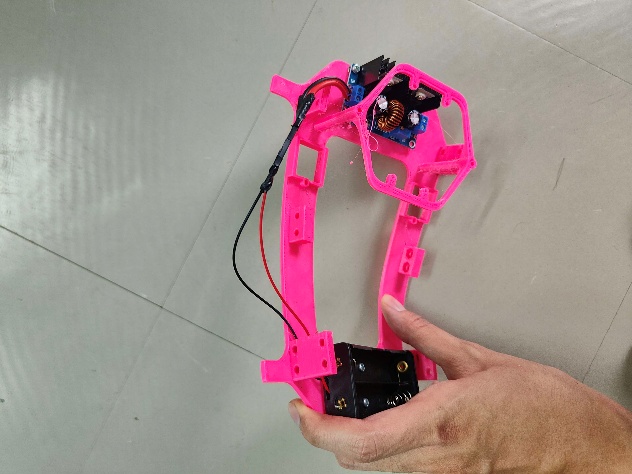
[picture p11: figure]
รูปภาพประกอบด้วย กล้อง, สายเคเบิล, คน, ในร่ม เนื้อหาที่สร้างโดย AI อาจไม่ถูกต้อง
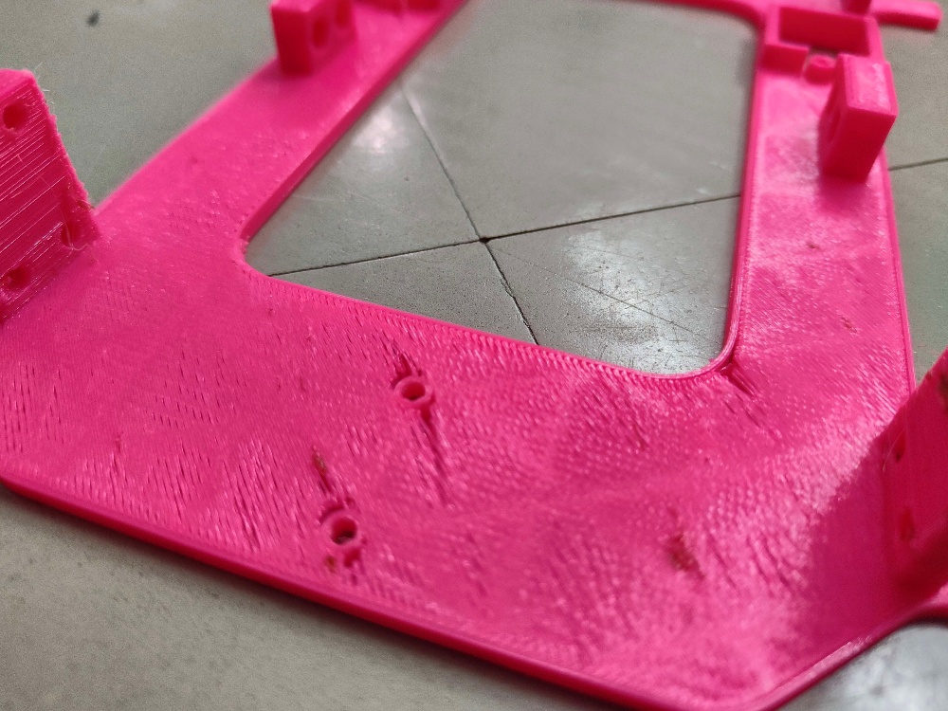
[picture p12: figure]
รูปภาพประกอบด้วย สีม่วงแดงเข้ม, สีชมพู, พื้น, ในร่ม เนื้อหาที่สร้างโดย AI อาจไม่ถูกต้อง

2. การปรับปรุงและการพิมพ์ชิ้นส่วนใหม่ (ครั้งที่สอง)
หลังจากที่พบปัญหาในการประกอบครั้งแรกแล้ว ผู้วิจัยได้ทำการปรับปรุงแบบ CAD และตั้งค่าเครื่องพิมพ์ 3D ใหม่ เพื่อแก้ไขปัญหาต่าง ๆ ที่พบ ได้แก่:

- ปรับปรุงขนาดรูยึดมอเตอร์: เนื่องจากครั้งแรกยังไม่มั่นใจในขนาดของมอเตอร์ที่แน่นอน จึงออกแบบให้มีรูหลายจุดสำหรับการยึด หลังจากได้รับมอเตอร์จริง จึงปรับ CAD ใหม่ให้เหลือรูเฉพาะตำแหน่งที่จำเป็นเท่านั้น

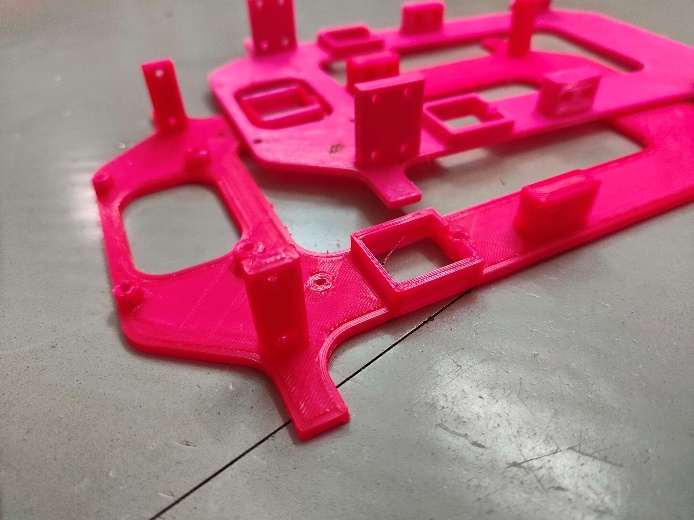
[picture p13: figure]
รูปภาพประกอบด้วย พื้น, ของเล่น เนื้อหาที่สร้างโดย AI อาจไม่ถูกต้อง

- การปรับขนาดรูสำหรับ XL4016: ตัว XL4016 มีจุดที่บัดกรีที่ยื่นออกมา ส่งผลให้ติดตั้งลงบนฐานได้ไม่สนิท ผู้วิจัยจึงออกแบบฐานใหม่ โดยเพิ่มส่วนที่คล้ายกับบูท (Spacer) เข้ามาเพื่อรองรับจุดบัดกรี ทำให้ XL4016 ยึดแน่นและเสถียรมากขึ้น
- การปรับปรุง Mouse Lock (ตัวยึดเมาส์): ชิ้นส่วน Mouse Lock เดิมพบว่ามีปัญหาด้านการใช้งานหลายอย่าง

-ความลึกของช่องสำหรับน็อตไม่เพียงพอ ทำให้น็อตไม่สามารถฝังตัวได้แนบสนิท

-ขนาดโดยรวมเล็กเกินไป ไม่สามารถยึดเมาส์ได้อย่างมั่นคง

-โครงสร้างแข็งเกินไปจนทำให้ประกอบยาก

ดังนั้นผู้วิจัยจึงทำการออกแบบ Mouse Lock ใหม่ โดยขยายขนาดให้สามารถรับเมาส์ได้พอดี, เพิ่มความลึกของช่องน็อต และปรับการออกแบบให้ประกอบง่ายขึ้น

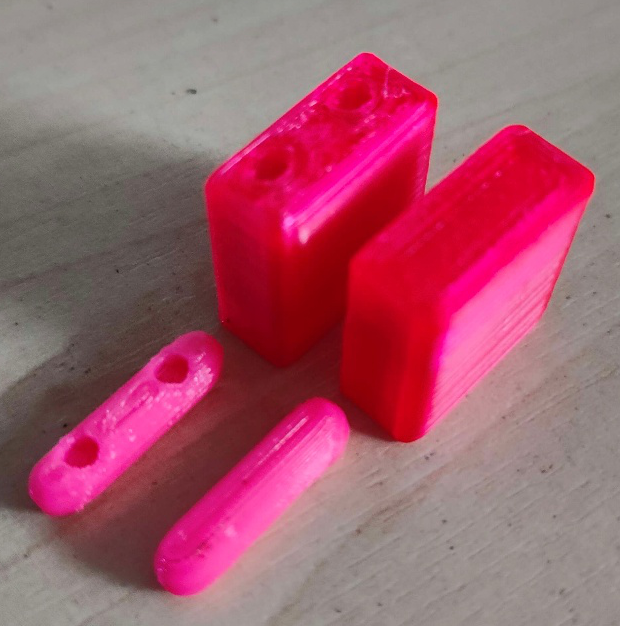
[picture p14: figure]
รูปภาพประกอบด้วย ของเล่น, พลาสติก, ชั้น, ในร่ม เนื้อหาที่สร้างโดย AI อาจไม่ถูกต้อง

3. การตั้งค่าแรงดันจาก XL4016:
ผู้วิจัยตั้งค่าแรงดันไฟฟ้าเอาต์พุตของ XL4016 ให้คงที่ที่ 7.4 V โดยเลือกแรงดันนี้เนื่องจากเป็นแรงดันที่เหมาะสมกับมอเตอร์ Yellow TT Motor และเป็นค่าแรงดันใกล้เคียงกับแรงดันแบตเตอรี่ลิเธียม 18650 สองก้อนอนุกรม เพื่อให้การจ่ายไฟมีความเสถียรและไม่ผันผวนมากเกินไป

อย่างไรก็ตาม หลังจากประกอบตัวหุ่นยนต์และเริ่มการทดสอบเบื้องต้น พบว่าแรงบิดของมอเตอร์ยังไม่เพียงพอต่อการควบคุมที่แม่นยำ โดยเฉพาะในช่วงความเร็วต่ำและการเริ่มเคลื่อนที่จากหยุดนิ่ง จึงได้มีการปรับเพิ่มแรงดันเอาต์พุตเป็น 7.77 V ซึ่งยังคงอยู่ในช่วงแนะนำของผู้ผลิต (6–8 V) และช่วยให้มอเตอร์มีแรงบิดสูงขึ้น ส่งผลให้หุ่นยนต์เคลื่อนที่ได้ราบรื่นและตอบสนองได้ดีขึ้นในระหว่างการควบคุม
(ทั้งนี้ ผู้วิจัยเลือกตั้งไว้ที่ 7.77 V เนื่องจากเป็นตัวเลขที่สื่อถึง "ความสมดุลในเชิงจิตวิทยา" และยังให้อารมณ์คล้ายเลขแจ็กพอตในตู้สล็อต)

4. การเชื่อมต่อสายไฟและการควบคุมมอเตอร์:
ESP32 38-pin ที่ใช้ในการควบคุมระบบหุ่นยนต์ ถูกเชื่อมต่อกับ Motor Driver (DRV8833) จำนวน 2 ตัว โดยแต่ละตัวจะควบคุมมอเตอร์จำนวน 2 ตัว (รวมทั้งหมด 4 มอเตอร์) การกำหนดพอร์ตที่เชื่อมต่อ ESP32 กับ DRV8833 มีดังนี้:

ESP32 Pin | DRV8833 Driver | Motor
GPIO 25, 26 | Driver ตัวที่ 1 | มอเตอร์ล้อหน้าซ้าย
GPIO 27, 14 | Driver ตัวที่ 1 | มอเตอร์ล้อหน้าขวา
GPIO 12, 13 | Driver ตัวที่ 2 | มอเตอร์ล้อหลังซ้าย
GPIO 32, 33 | Driver ตัวที่ 2 | มอเตอร์ล้อหลังขวา

หมายเหตุ: การเลือก GPIO ดังกล่าวเป็นการเลือกจากพอร์ตที่สะดวกต่อการเดินสายและเหมาะสมสำหรับ PWM ที่ใช้ควบคุมมอเตอร์ผ่าน DRV8833

5. ภาพแสดงการประกอบเสร็จสมบูรณ์:

หลังจากปรับปรุงและประกอบใหม่เรียบร้อยแล้ว ระบบหุ่นยนต์มีลักษณะและการจัดวางอุปกรณ์ที่เหมาะสม และมีความแข็งแรงเพียงพอสำหรับการทดสอบการทำงานในขั้นตอนถัดไป โดยภาพด้านล่างนี้แสดงหุ่นยนต์จากหลายมุมมองที่รวมอยู่ในรูปเดียว เพื่อแสดงรายละเอียดของการประกอบโดยรวม

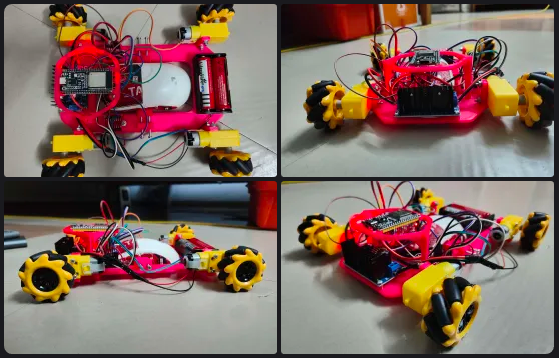
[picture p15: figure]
รูปภาพประกอบด้วย ล้อ, ของเล่นรถ, ของเล่น, ของเล่นบังคับวิทยุ เนื้อหาที่สร้างโดย AI อาจไม่ถูกต้อง

### 3.4.4 การทดสอบระบบการเคลื่อนที่ของหุ่นยนต์เบื้องต้น (Preliminary Mobility Test)

หลังจากประกอบชิ้นส่วนฮาร์ดแวร์ทั้งหมดตามแบบ CAD และทำการตรวจสอบความแข็งแรงของโครงสร้างเรียบร้อยแล้ว ผู้วิจัยได้ดำเนินการทดสอบเบื้องต้นเพื่อยืนยันว่าการเชื่อมต่อของมอเตอร์และล้อแบบ Mecanum ทำงานได้ถูกต้องในทุกทิศทางที่ออกแบบไว้

วัตถุประสงค์ของการทดสอบ

- ตรวจสอบการหมุนของมอเตอร์ทั้ง 4 ตัวว่าเชื่อมต่อและทำงานได้อย่างถูกต้อง
- ทดสอบพฤติกรรมการเคลื่อนที่ของหุ่นยนต์ในแต่ละทิศทางพื้นฐานของล้อ Mecanum ได้แก่ เดินหน้า ถอยหลัง สไตรฟซ้าย/ขวา หมุนซ้าย/ขวา และการเคลื่อนที่เฉียง
- ยืนยันว่า ESP32 สามารถควบคุมการทำงานของมอเตอร์ผ่านสัญญาณดิจิทัลได้อย่างแม่นยำ

ESP32 ถูกตั้งโปรแกรมโดยใช้ Arduino Framework (C++) โดยใช้ digitalWrite กับ GPIO 8 ขา เพื่อควบคุมทิศทางของมอเตอร์ทั้ง 4 ตัว แต่ละคำสั่งจะสั่งให้หุ่นยนต์เคลื่อนที่ในทิศทางต่าง ๆ ทีละ 500 มิลลิวินาที และหยุดชั่วคราวก่อนเปลี่ยนทิศทาง

ทิศทางที่ทดสอบ ได้แก่:

1. เดินหน้า (Forward)
2. ถอยหลัง (Backward)
3. สไตรฟขวา / ซ้าย (Strafe Right / Left)
4. หมุนขวา / ซ้าย (Rotate Right / Left)
5. เคลื่อนที่เฉียง 4 มุม (Diagonal Movement)

ตัวอย่างโค้ดสำหรับทดสอบการหมุนขวา(test.cpp) :

เมื่อทดสอบครบแล้ว จะเข้าสู่การหยุดการทำงานโดยให้ loop หลักสิ้นสุด (while (true) delay(1000);) เพื่อป้องกันการวนซ้ำโดยไม่จำเป็น

ผลการทดสอบเบื้องต้น

- มอเตอร์ทั้ง 4 ตัวทำงานได้ตามที่ตั้งค่าไว้
- หุ่นยนต์สามารถเคลื่อนที่ในทุกทิศทางตามคำสั่งโดยไม่มีอาการผิดปกติ
- ความคลาดเคลื่อนในการหมุนอยู่ในเกณฑ์ที่ยอมรับได้สำหรับการใช้งานเบื้องต้น โดยไม่มี encoder
- การตอบสนองของระบบไฟฟ้าเมื่อเปลี่ยนทิศทางมีความต่อเนื่องดี ไม่มีอาการหน่วง

ข้อสังเกต

- ไม่มีการวัดค่าระยะหรือความเร็วโดยตรงจาก feedback เพราะมอเตอร์ที่ใช้เป็นแบบไม่มี encoder
- ความแม่นยำของการควบคุมระยะจะต้องถูกประเมินจากการผสานระบบในภายหลังโดยใช้ Inverse Kinematics และระยะเป้าหมายจากระบบ Vision

## 3.5 การพัฒนาแอปพลิเคชันสำหรับการตรวจจับเป้าหมาย

### 3.5.1 การพัฒนาแอปพลิเคชันสำหรับการตรวจจับเป้าหมาย (Target Detection App Development)

ในส่วนนี้ ผู้วิจัยได้พัฒนาแอปพลิเคชันหลักด้วยภาษา Python สำหรับควบคุมกระบวนการทำงานของระบบตรวจจับเป้าหมายทั้งหมด ตั้งแต่การจับภาพหน้าจอเกม Kovaak ไปจนถึงการตรวจจับ ตีความตำแหน่งเป้าหมาย และเตรียมข้อมูลเพื่อนำไปควบคุมหุ่นยนต์จริงในขั้นตอนถัดไป โดยมุ่งเน้นให้ระบบสามารถแสดงผลแบบ Real-time ได้อย่างชัดเจน มีการสลับโหมดการทำงาน และมีหน้าจอแสดงข้อมูลสำคัญในการเล็งเป้า

โครงสร้างของโปรแกรม

แอปพลิเคชันนี้ประกอบด้วย 4 ไฟล์หลัก:

- main.py (จุดเริ่มต้นโปรแกรม)
- capture.py (ใช้เลือกหน้าต่าง Kovaak และจับภาพหน้าจอ)
- detect.py (โหลดโมเดล YOLOv5 และรัน Inference)
- distance.py (คำนวณระยะห่างและมุมของเป้าหมายจากจุดศูนย์กลาง)

โดยผู้ใช้สามารถเริ่มรันโปรแกรมได้ทันที และควบคุมโหมดการทำงานได้ผ่านปุ่มคีย์บอร์ด:

- กด W → Mode 0 (ไม่ทำอะไร)
- กด E → Mode 1 (ติดตามเป้าหมายอย่างเดียว)
- กด R → Mode 2 (เตรียมยิงเมื่อเป้าอยู่กลางจอ)

ฟีเจอร์หลักของระบบ

- ระบบตรวจจับเป้าหมายอัตโนมัติ: โปรแกรมจะใช้ YOLOv5 ตรวจจับเป้าหมายในภาพจากหน้าจอ และเลือกเป้าหมายที่ใกล้ศูนย์กลางที่สุด
- เลือกหน้าต่างเกม (Game Window Selection): เมื่อเริ่มต้นระบบ ผู้ใช้สามารถเลือกหน้าต่างของเกมที่ต้องการจากรายการหน้าต่างที่เปิดอยู่ได้ (ใช้ pygetwindow) เพื่อให้มั่นใจว่าระบบจะจับภาพจากหน้าต่างที่ถูกต้องเท่านั้น
- แสดงระยะ (Distance) และมุม (Angle): หลังจากตรวจจับเป้าหมายได้แล้ว ระบบจะคำนวณระยะห่าง (เป็นพิกเซล) และมุม (0° = ขึ้น, 90° = ขวา, 180° = ลง) ไปยังจุด "หน้าอก" ของเป้าหมาย
- On-Target Detection: หากเป้าอยู่ภายในกล่องกลางหน้าจอ (bounding box) จะถือว่า "On Target"
- แสดงข้อมูลบนหน้าจอ: แสดงข้อมูลสำคัญทางด้านซ้ายบนของหน้าจอ เช่น Mode, Distance, Angle และสถานการณ์เล็ง

ตัวอย่างโค้ดที่สำคัญ:

การเลือกหน้าต่างที่ต้องการ:

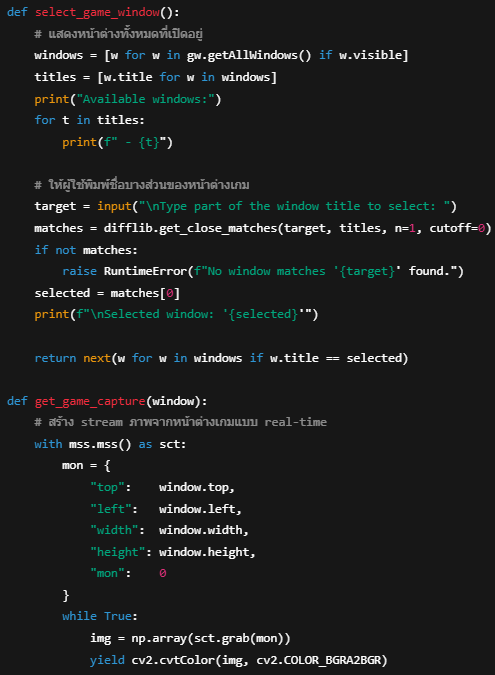
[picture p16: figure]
รูปภาพประกอบด้วย ข้อความ, ภาพหน้าจอ, ซอฟต์แวร์ เนื้อหาที่สร้างโดย AI อาจไม่ถูกต้อง

-ฟังก์ชัน select_game_window() จะค้นหาและแสดงชื่อหน้าต่างทั้งหมดที่เปิดอยู่

-ผู้ใช้สามารถพิมพ์ชื่อเกม เช่น "KovaaK" เพื่อตรงกับชื่อหน้าต่าง

-ระบบจะจับภาพเฉพาะในพื้นที่หน้าต่างนั้นแบบ real-time โดยใช้ mss

-ภาพที่ได้ถูกส่งออกแบบ generator frame-by-frame

การเลือกเป้าหมายที่ใกล้ศูนย์กลางที่สุด:

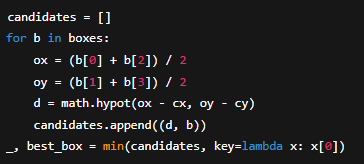
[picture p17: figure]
รูปภาพประกอบด้วย ข้อความ, ภาพหน้าจอ, ตัวอักษร เนื้อหาที่สร้างโดย AI อาจไม่ถูกต้อง

การคำนวณระยะและมุมไปยัง “หน้าอก” ของเป้าหมาย:

การแสดงผลบนหน้าจอ:

สรุปการทำงาน

ในขั้นตอนนี้ผู้วิจัยได้สร้างแอปพลิเคชันสำหรับตรวจจับเป้าหมายจากหน้าจอจริง พร้อมแสดงผลข้อมูลที่เกี่ยวข้องและควบคุมโหมดการทำงานของระบบได้แบบโต้ตอบ เพื่อเตรียมพร้อมสำหรับการเชื่อมต่อกับระบบหุ่นยนต์จริงในขั้นตอนถัดไป

### 3.5.2 การพัฒนาและปรับปรุงระบบการควบคุมคลิก (Clicking Control Refinement)

เดิมทีผู้วิจัยวางแผนที่จะใช้ ESP32 ส่งคำสั่งคลิกผ่าน Bluetooth กลับมายัง PC แต่พบว่าแนวทางดังกล่าวต้องอาศัยการเชื่อมต่อและการตั้งค่าระบบเพิ่มเติมหลายขั้นตอน เช่น การจับคู่ Bluetooth, ความหน่วงในการส่งข้อมูล และความยุ่งยากในการทดสอบเบื้องต้น โดยเฉพาะเมื่อเป้าอยู่บนหน้าจอเกมและต้องส่งคำสั่งคลิกแบบทันที

เพื่อความสะดวกและลดความซับซ้อนในการทดลองช่วงแรก จึงเปลี่ยนมาใช้แนวทางการ “จำลองการคลิกด้วยซอฟต์แวร์” โดยใช้ไลบรารี pynput.mouse เพื่อจำลองการกดและปล่อยคลิกซ้ายแบบอัตโนมัติเมื่อเงื่อนไขตรงกับเป้าหมายที่ตรวจจับได้

แนวทางที่เลือกใช้: Python Mouse Emulation

โดยใช้ไลบรารี pynput.mouse ผู้วิจัยสามารถจำลองการคลิกเมาส์ได้โดยตรงจาก Python ทำให้สามารถควบคุมการคลิกได้ทันทีเมื่อมีการตรวจจับเป้าหมายบนหน้าจอ เช่น:

- mouse.press(Button.left)
- mouse.release(Button.left)

ปัญหาการควบคุมโหมดผ่านคีย์บอร์ด

ในระยะแรกของการพัฒนา โปรแกรมใช้วิธีอ่านค่าเฉพาะเมื่อหน้าต่างแอปพลิเคชัน “Aimbot View” อยู่ด้านหน้าเท่านั้น ทำให้เมื่อต้องควบคุมเกมจริงพร้อมกับแสดงหน้าต่างตรวจจับ (เช่น เมื่อสลับกลับไปยังหน้าจอเกม Kovaak) ระบบจะไม่สามารถรับคำสั่งจากคีย์บอร์ดได้อีกต่อไป

เพื่อแก้ปัญหาดังกล่าว ผู้วิจัยจึงตัดสินใจเปลี่ยนแนวทางเป็นการ “ตรวจจับคีย์บอร์ดตลอดเวลา (global keyboard hook)” โดยใช้ไลบรารี keyboard ซึ่งสามารถจับทุกการกดปุ่มแม้โปรแกรมจะทำงานเบื้องหลัง โดยมีข้อกำหนดว่าต้องรันด้วยสิทธิ์ Administrator และติดตั้งไลบรารีด้วยคำสั่ง:

อย่างไรก็ตาม เมื่อเปิดระบบให้จับคีย์ตลอดเวลา กลับพบปัญหาใหม่ คือปุ่มที่เดิมใช้ควบคุมโมดูล (W, E, R) ถูกใช้งานโดยตัวเกม Kovaak เอง เช่น:

- W → ใช้เดินหน้า
- R → ใช้ Reload

การกดปุ่มควบคุมโปรแกรมจึงรบกวนการเล่นเกมโดยตรง

แนวทางแก้ไข:

ผู้วิจัยจึงเปลี่ยนไปใช้ปุ่มที่ไม่ถูกใช้งานในตัวเกมแทน โดยกำหนดปุ่มใหม่ดังนี้:

- Z → Quit (ออกจากโปรแกรม)
- X → Mode 0 (Idle – ไม่ทำงาน)
- C → Mode 1 (Tracking – คลิกค้างเมื่อเล็งได้)
- V → Mode 2 (Click Pulse – คลิกเป็นจังหวะเมื่อเล็งได้)

แนวทางใหม่นี้ช่วยให้สามารถควบคุมการทำงานของระบบได้สะดวกยิ่งขึ้นในระหว่างเล่นเกมจริง โดยไม่ไปรบกวนการควบคุมเกมของผู้เล่น

การจำลองคลิกแบบ Pulse (Mode 2)

เพื่อเลียนแบบการคลิกของมนุษย์ในจังหวะยิง ผู้วิจัยได้ออกแบบระบบใน Mode 2 ให้:

- คลิกเมื่อเป้าอยู่ในตำแหน่งที่กำหนด (On Target)
- รอ delay 26ms → release → delay 27ms → คลิกใหม่

โค้ดนี้จะช่วยให้ระบบทำงานได้แบบ responsive และใกล้เคียงกับการคลิกจริงมากที่สุด โดยไม่ต้องพึ่งพา ESP32 ในการควบคุมคลิก

การออกแบบในส่วนของซอฟต์แวร์ถือว่าเสร็จสมบูรณ์ในขั้นนี้แล้ว โดยส่วนถัดไปคือการส่งข้อมูลระยะและมุมไปยัง ESP32 และพัฒนาระบบควบคุมการเคลื่อนที่จริงให้สอดคล้องกับค่าที่ได้รับ

## 3.6 การผสานระบบ (System Integration)

### 3.6.1 การทดสอบการส่งข้อมูลผ่าน PySerial เบื้องต้น

วัตถุประสงค์ของการทดลอง

เพื่อทดสอบความสามารถในการเชื่อมต่อและส่งข้อมูลจากฝั่งแอปพลิเคชัน (Python) ไปยัง ESP32 ผ่านพอร์ตอนุกรม (Serial Port) โดยจำลองการส่งข้อมูล 4 ค่า ได้แก่:

- Distance (หน่วยพิกเซล): ระยะห่างระหว่างจุดศูนย์กลางหน้าจอกับจุดเล็ง
- Angle (องศา): มุมของเป้าหมายจากแนวแกนตั้งฉาก
- On Target (บูลีน): 1 ถ้าเป้าอยู่ในกรอบ On-Target
- Mode (โหมดการทำงาน เช่น Tracking / Clicking)

โครงสร้างระบบที่ใช้ในการทดสอบ

ฝั่ง Python:

- ใช้คลาส SerialSender จากไฟล์ serial_sender.py เพื่อเปิดการเชื่อมต่อ Serial และส่งข้อมูลตามรูปแบบ
- ตัวอย่างข้อมูลที่ส่งออก:

ซึ่งแทน Distance = 45, Angle = 89.5, OnTarget = True, Mode = 2 (Clicking)

# ตัวอย่างใน serial_sender.py

ฝั่ง ESP32:

- เขียนโปรแกรมด้วย Arduino C++ (main.cpp) โดยเปิด Serial ที่ 115200 baud และใช้คำสั่ง Serial.parseFloat() และ Serial.parseInt() เพื่อแยกค่าที่ส่งมา
- ระบบจะแสดงผลผ่าน Serial Monitor และเลือกการเคลื่อนที่ตาม mode:
  - mode = 1 → เคลื่อนที่ไปข้างหน้า
  - mode = 2 → ถอยหลัง
  - ค่าอื่น → หยุดทั้งหมด

ผลการทดสอบ

จากการทดสอบพบว่า:

- สามารถเปิดพอร์ต Serial ได้อย่างถูกต้องผ่าน SerialSender และรับค่าที่ถูกต้องบนฝั่ง ESP32
- ค่าที่ส่งออกมาสามารถแสดงผ่าน Serial Monitor บน Arduino ได้ทันทีและนำไปควบคุมมอเตอร์ได้ตามคำสั่ง

ปัญหาที่พบและข้อจำกัดของการใช้งานจริง

แม้ระบบจะทำงานได้เบื้องต้น แต่มีข้อจำกัดสำคัญคือ:

1. Serial Port Conflict: หากต้องการ Upload โปรแกรมใหม่ขึ้น ESP32 ขณะที่แอปพลิเคชันยังรันอยู่ จะต้อง:
  - ปิดแอปเพื่อปลดพอร์ต
  - ถอดสาย USB และกดปุ่ม BOOT ที่บอร์ด ESP32 ค้างไว้
  - เสียบใหม่เพื่อให้พอร์ตว่างสำหรับอัปโหลด

ซึ่งกระบวนการนี้เสียเวลาและมีโอกาสเกิดข้อผิดพลาดสูงเมื่อทดสอบหลายรอบ

2. ไม่เหมาะกับงานที่ต้องการปรับค่าบ่อย เช่น การจูน PID: การทดสอบค่า PID แต่ละรอบอาจต้องส่งค่าใหม่ไปยัง ESP32 → อัปโหลดใหม่ → ทดสอบ ซึ่งจะเสียเวลามากหากทำแบบนี้หลายครั้ง

แนวทางแก้ไขและการวางแผนต่อไป

ผู้วิจัยจึงมีแผนจะ ย้ายการคำนวณทั้งหมด (รวมถึง PID) กลับมาทำฝั่ง Python โดยให้:

- Python คำนวณความเร็วของมอเตอร์แต่ละล้อ
- ส่งความเร็วของล้อ (เช่น V_FL, V_FR, V_RL, V_RR) เป็น Serial string ไปยัง ESP32
- ESP32 ทำหน้าที่เป็นเพียงตัว "สั่ง PWM" ตามค่าที่ได้รับ ไม่ต้องคิด logic ใด ๆ

ข้อดีของแนวทางนี้:

- ไม่ต้องอัปโหลดโค้ดใหม่บ่อย
- สามารถปรับค่าทดลองได้ทันทีจากแอป
- รองรับการจูน PID หรือเทคนิค Optimization ได้สะดวกกว่า

### 3.6.2 การทดสอบและปรับเทียบค่าควบคุมความเร็วขั้นต่ำของมอเตอร์ (Minimum Speed Calibration)

วัตถุประสงค์ของการทดสอบ

เนื่องจากมอเตอร์แบบ Yellow TT Motor ที่ใช้งานร่วมกับไดรเวอร์ DRV8833 ไม่มี feedback encoder จึงไม่สามารถวัดความเร็วเชิงปริมาณได้โดยตรง ผู้วิจัยจึงต้องทำการทดลองหา ค่า PWM ขั้นต่ำ ที่สามารถทำให้มอเตอร์เริ่มหมุนได้จริง

ผลลัพธ์จากการทดลองนี้จะถูกนำไปใช้ในการ:

- แปลงค่าความเร็วจากโมดูล Inverse Kinematics (ค่าปกติอยู่ในช่วง -1.0 ถึง +1.0) ไปเป็นสัญญาณ PWM ที่มอเตอร์สามารถใช้งานได้จริง
- ป้องกันไม่ให้เกิดการส่งค่า PWM ที่ “น้อยเกินไป” ซึ่งไม่สามารถทำให้ล้อหมุน ส่งผลให้ระบบหยุดนิ่งหรือเกิดอาการ jitter โดยไม่เคลื่อนที่

ขั้นตอนการทดลอง

1. เขียนโปรแกรม Python (minspeedtest.py) สำหรับปรับค่าความเร็วของมอเตอร์แต่ละตัวแบบ real-time โดยการกดปุ่มบนคีย์บอร์ด เพื่อเพิ่มหรือลดค่า PWM ทีละ 1 หน่วย
2. ตั้งค่าพื้นฐานของมอเตอร์ทุกตัวที่ PWM = 30
3. วัดค่าที่มอเตอร์เริ่ม "หมุนต่อเนื่องได้ด้วยตัวเอง" โดยไม่มีการหมุนช่วย
4. วัดค่าที่มอเตอร์ “สามารถหมุนได้หลังจากถูกแตะเบา ๆ” (เพื่อประเมินค่าที่เอาชนะ Torque Stall ได้)
5. ทำซ้ำทั้ง 4 ล้อ เพื่อดูความสม่ำเสมอของระบบ
6. สรุปค่าเฉลี่ย และใช้ค่านั้นในการแปลง (mapping) ความเร็วเชิงทฤษฎีเป็น PWM จริงในระบบ

สรุปผลการทดลอง

- มอเตอร์เริ่มหมุนต่อเนื่อง ที่ PWM ≈ 145
- หากช่วยหมุนล้อเบา ๆ → มอเตอร์สามารถทำงานได้ที่ PWM ≈ 135
- จึงเลือกใช้ ค่าขั้นต่ำในการหมุนจริง = 140

โค้ดสำคัญในการทดลอง

Python (PC side): โปรแกรมจะส่งความเร็ว 4 ล้อผ่าน PySerial ไปยัง ESP32 ทุก 50ms

ESP32 (C++): รับข้อความและแปลงเป็นความเร็ว PWM แยกข้าง พร้อมควบคุมผ่าน PWM

### 3.6.3 การพัฒนาโปรแกรมควบคุมมอเตอร์ ESP32 แบบ Mapping ความเร็วจากเปอร์เซ็นต์

หลังจากที่ได้ดำเนินการทดลองเพื่อหา ค่าความเร็วขั้นต่ำ (Minimum PWM) ที่ทำให้มอเตอร์เริ่มหมุนได้จริง (อ้างอิงจาก 3.6.2) ผู้วิจัยจึงได้นำผลการทดลองมาพัฒนาโปรแกรมฝั่ง ESP32 ให้สามารถ รับค่าความเร็วในรูปแบบเปอร์เซ็นต์ (–100 ถึง +100) และแปลงเป็นสัญญาณ PWM ที่เหมาะสมกับลักษณะการทำงานจริงของมอเตอร์

วัตถุประสงค์ของการพัฒนา

- ทำให้การส่งค่าความเร็วจากฝั่ง Python เป็น ค่าทางตรรกะ (Logical Speed) ที่ไม่ขึ้นอยู่กับค่า PWM จริง
- แยกการปรับ PID, Inverse Kinematics, และการควบคุมฮาร์ดแวร์ออกจากกันอย่างชัดเจน
- ลดเวลาในการอัปโหลดโปรแกรมบ่อย ๆ เนื่องจากผู้วิจัยพบว่า การสลับระหว่างการส่งข้อมูลและการอัปโหลดโปรแกรมลง ESP32 ใช้เวลานานและยุ่งยาก

หลักการ Mapping ค่าความเร็ว

จากการทดลอง พบว่า PWM ต้องมากกว่า 140 ถึงจะทำให้มอเตอร์เริ่มหมุนได้

ดังนั้นจึงกำหนดว่า:

- ความเร็วตรรกะ +1 → PWM จริง = 140
- ความเร็วตรรกะ +100 → PWM จริง = 255
- ความเร็วตรรกะ 0 → PWM จริง = 0
- ความเร็วตรรกะ –1 → PWM จริง = –140
- ความเร็วตรรกะ –100 → PWM จริง = –255

ฟังก์ชันการ Mapping สามารถเขียนเป็นสมการดังนี้:

สำหรับค่าความเร็ว v (อยู่ในช่วง –100 ≤ v ≤ 100):

หาก v > 0:

pwm = map(v, 1, 100, 140, 255)

หาก v < 0:

pwm = -map(abs(v), 1, 100, 140, 255)

หาก v == 0:

pwm = 0

โดยใช้ฟังก์ชัน map() ของ Arduino ซึ่งทำการแปลงค่าในช่วงหนึ่งไปยังอีกช่วงหนึ่งแบบ Linear

โค้ดสำคัญที่พัฒนาใน ESP32 (main.cpp)

1. ฟังก์ชัน percentToPwm():
  - ใช้ในการแปลงความเร็วจาก –100…+100 ไปเป็น PWM จริง โดยมี "Deadzone" ต่ำกว่า ±140 ตัดทิ้ง
2. ฟังก์ชัน driveMotor():

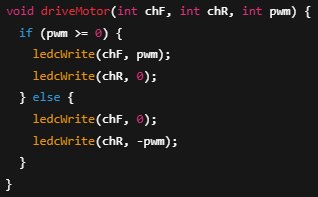
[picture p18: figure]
รูปภาพประกอบด้วย ข้อความ, ภาพหน้าจอ, ตัวอักษร, ออกแบบ เนื้อหาที่สร้างโดย AI อาจไม่ถูกต้อง

  - รับค่า PWM และแยกทิศทาง (forward/reverse) เพื่อเขียนค่าผ่าน PWM Channel
3. การรับค่าผ่าน Serial (Python → ESP32):

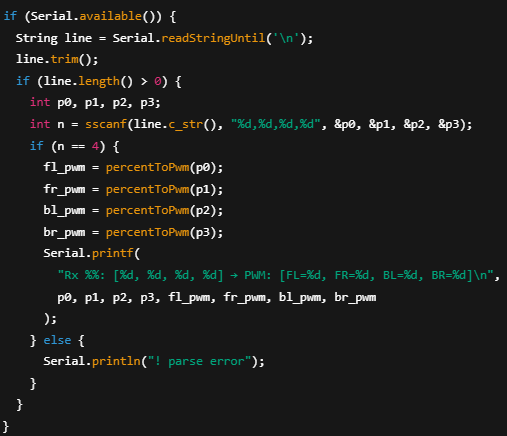
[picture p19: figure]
รูปภาพประกอบด้วย ข้อความ, ภาพหน้าจอ, ซอฟต์แวร์, ตัวอักษร เนื้อหาที่สร้างโดย AI อาจไม่ถูกต้อง

  - ESP32 จะอ่านข้อมูลเป็นสายข้อความลักษณะ "p0,p1,p2,p3\n" แทนค่าความเร็วของล้อทั้ง 4 ล้อ (FL, FR, BL, BR)
  - ตัวอย่าง: "0,30,50,-70\n" จะถูกแปลงเป็น PWM ตาม percentToPwm()
4. Loop การทำงาน:
  - ESP32 จะ re-apply ค่าความเร็วล่าสุดทุก 10 ms (100 Hz refresh rate)
- สามารถส่งค่าความเร็วจากฝั่งคอมพิวเตอร์ได้อย่างยืดหยุ่นและเข้าใจง่าย
- ลดความยุ่งยากในการ tuning เพราะสามารถควบคุมด้วยค่า logic ที่อยู่ในช่วง –100 ถึง +100
- ทำให้การควบคุมและการทดลอง PID ในขั้นถัดไปสามารถทำได้เร็วขึ้นโดยไม่ต้องอัปโหลดโปรแกรมลง ESP32 ใหม่ทุกครั้ง
- ปรับเปลี่ยนค่าความเร็ว และทดสอบการตอบสนองของหุ่นยนต์ในแต่ละทิศทางได้ง่าย

### 3.6.4 การคำนวณ Inverse Kinematics และการผสานระบบเบื้องต้น

หลังจากที่ระบบสามารถตรวจจับตำแหน่งเป้าหมายจากกล้องหน้าจอและแสดงผลผ่านอินเทอร์เฟซได้อย่างสมบูรณ์ ผู้วิจัยได้ดำเนินการต่อเนื่องโดยเริ่มต้นนำผลการตรวจจับไปใช้ควบคุมทิศทางของหุ่นยนต์จริง โดยใช้หลักการ Inverse Kinematics สำหรับล้อแบบ Mecanum ทั้ง 4 ล้อ

วัตถุประสงค์

- แปลงค่าความคลาดเคลื่อนของตำแหน่งเป้าหมายบนหน้าจอ (ค่าระยะพิกเซลในแนวแกน X, Y) ให้เป็นคำสั่งความเร็วของล้อทั้ง 4
- ใช้สมการ Inverse Kinematics เพื่อแยกคำสั่งเคลื่อนที่ในแต่ละทิศทาง (เดินหน้า, ถอยหลัง, เลี้ยว, สไตรฟ) ให้กลายเป็นความเร็วที่ต้องใช้ในล้อแต่ละข้าง
- แปลงค่าความเร็วให้อยู่ในรูปแบบเปอร์เซ็นต์ (–100% ถึง +100%) เพื่อส่งออกผ่าน Serial ไปยัง ESP32

หลักการและสมการที่ใช้

การคำนวณ Inverse Kinematics สำหรับหุ่นยนต์ที่ใช้ล้อ Mecanum โดยทั่วไปจะมีพารามิเตอร์ด้านเรขาคณิตของหุ่นยนต์ (เช่น ความยาว, ความกว้าง, รัศมีล้อ ฯลฯ) แต่ในระบบนี้เพื่อความเรียบง่ายและลดความซับซ้อนเบื้องต้น จึงใช้ “Normalised Inverse Kinematics” โดยไม่พิจารณาขนาดจริงของล้อหรือเฟรมหุ่นยนต์

หากกำหนด:

- Vx = ความเร็วการเคลื่อนที่ตามแกน X (ขวา+ ซ้าย–)
- Vy = ความเร็วการเคลื่อนที่ตามแกน Y (หน้า+ หลัง–)
- ω = ความเร็วเชิงมุม (หมุนซ้าย+ ขวา–)

เราสามารถคำนวณความเร็วของล้อทั้ง 4 ได้ดังนี้:

V_FL = Vy + Vx + ω

V_FR = Vy - Vx - ω

V_BL = Vy - Vx + ω

V_BR = Vy + Vx – ω

ซึ่งในระบบนี้ ω = 0 เพราะยังไม่มีการหมุนหุ่นยนต์รอบตัวเอง

การแปลงสมการเป็นโค้ด

สมการ Inverse Kinematics ถูกแปลงเป็นฟังก์ชันในไฟล์ kinematics.py ดังนี้:

การทำ Normalisation และจำกัดความเร็วล้อ

หลังจากได้ค่าความเร็วเบื้องต้นของแต่ละล้อแล้ว จะมีการแปลงให้อยู่ในช่วง –100% ถึง +100% โดยใช้ฟังก์ชัน normalize:

ขั้นตอนนี้ช่วยให้ความเร็วล้อใด ๆ จะไม่เกินค่าความเร็วสูงสุดที่กำหนด (เช่น 100%) และรักษาสัดส่วนความเร็วของล้ออื่น ๆ ตามไปด้วย

การส่งค่าความเร็วล้อไปยัง ESP32

เมื่อได้ค่าความเร็วล้อในรูปแบบเปอร์เซ็นต์แล้ว จะทำการปรับทิศทางการหมุน (ตามการเดินสายจริงของมอเตอร์แต่ละตัว) และส่งค่าผ่าน Serial ไปยัง ESP32 โดยใช้คลาส SerialSender ในไฟล์ serial_sender.py:

โดยฟังก์ชัน send_wheels() จะทำการเขียนข้อความที่ประกอบด้วยความเร็วของล้อทั้ง 4 เป็นข้อความแยกด้วยเครื่องหมายจุลภาค เช่น:

ตัวอย่างโค้ดที่เกี่ยวข้อง

ใน main.py:

ใน wheel_control.py:

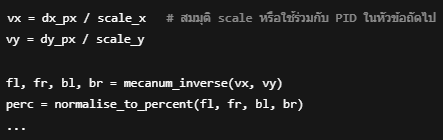
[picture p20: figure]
รูปภาพประกอบด้วย ข้อความ, ตัวอักษร, ภาพหน้าจอ, สีดำ เนื้อหาที่สร้างโดย AI อาจไม่ถูกต้อง

สรุป

การผสานระบบด้วย Inverse Kinematics ช่วยให้สามารถนำค่าการตรวจจับเป้าหมายจากหน้าจอไปควบคุมทิศทางการเคลื่อนที่ของหุ่นยนต์ได้โดยตรงในระยะเบื้องต้น เพื่อนำไปพัฒนาระบบ PID tuning ที่แม่นยำยิ่งขึ้นในหัวข้อถัดไป

### 3.6.5 การพัฒนาและปรับแต่ง PID Controller สำหรับการควบคุมทิศทางและระยะ

วัตถุประสงค์ของระบบควบคุม PID

ระบบ PID (Proportional-Integral-Derivative) ถูกนำมาใช้ในโครงการนี้เพื่อควบคุมการเคลื่อนที่ของหุ่นยนต์ให้ตอบสนองต่อเป้าหมายอย่างแม่นยำ โดยเฉพาะในส่วนของการควบคุมทิศทางการเคลื่อนที่ทั้งในแกน X (Strafe) และแกน Y (Forward/Backward)

PID Controller จะรับค่า “ความคลาดเคลื่อนของตำแหน่ง” (Pixel Error) ที่เกิดจากการเปรียบเทียบตำแหน่งเป้าหมายบนหน้าจอ (จาก YOLOv5) กับจุดศูนย์กลางหน้าจอ แล้วคำนวณความเร็วที่เหมาะสมเพื่อให้หุ่นยนต์เคลื่อนไปยังตำแหน่งเป้าหมายนั้น

สมการ PID ที่ใช้

ค่าสั่งการ (Output) ของ PID สามารถคำนวณได้จาก:

u(t) = Kp * e(t) + Ki * ∫ e(t) dt + Kd * d(e(t))/dt

โดยที่:

- u(t) คือ ค่าคำสั่งสุดท้าย (output velocity)
- e(t) คือ ความคลาดเคลื่อนของตำแหน่งในช่วงเวลาปัจจุบัน (current error)
- Kp คือ ค่าขยายของสัดส่วน (Proportional Gain)
- Ki คือ ค่าขยายของผลรวม (Integral Gain)
- Kd คือ ค่าขยายของอนุพันธ์ (Derivative Gain)

ในโปรแกรมจะใช้ตัวแปร dx_px และ dy_px แทนความคลาดเคลื่อนในแนวแกน X และ Y ตามลำดับ โดยถูกประมวลผลผ่าน PID แต่ละชุดเพื่อคำนวณ vx, vy ที่เป็นอินพุตสำหรับระบบ Inverse Kinematics ต่อไป

การนำ PID ไปใช้ในโค้ด

โครงสร้าง PID อยู่ในไฟล์ pid.py:

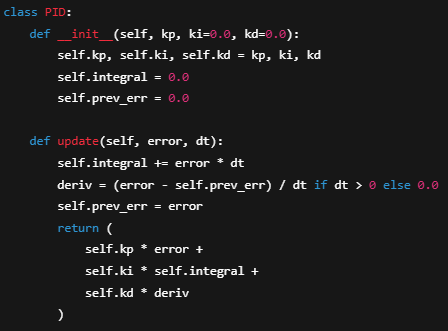
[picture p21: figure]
รูปภาพประกอบด้วย ข้อความ, ภาพหน้าจอ, ตัวอักษร เนื้อหาที่สร้างโดย AI อาจไม่ถูกต้อง

และถูกเรียกใช้ใน wheel_control.py ผ่านฟังก์ชัน pixel_error_to_wheels():

ผลลัพธ์ vx และ vy จะถูกส่งต่อไปยัง mecanum_inverse() เพื่อแปลงเป็นค่าความเร็วของล้อแต่ละตัว

การเตรียมสำหรับการปรับแต่ง (PID Tuning)

เพื่อให้ระบบมีประสิทธิภาพสูงสุด จะต้องมีการ “จูน” ค่า Kp, Ki, Kd ให้เหมาะสมกับลักษณะการเคลื่อนไหวจริงของหุ่นยนต์ โดยขั้นตอนที่ใช้มีดังนี้:

ข้อมูลเบื้องต้น:

- DPI ของเมาส์: 800 DPI (ไม่สามารถเปลี่ยนได้เพราะไม่มีซอฟต์แวร์)
- อัตรารีเฟรช: 1000 Hz polling rate
- Resolution เกม: 1920×1080 (Full HD)
- เป้าหมาย: ต้องการปรับเซนส์ให้อยู่ในระดับที่หุ่นยนต์สามารถเล็งเป้าได้แม่นยำและเร็วพอในพื้นที่จำกัด

การเลือก Sensitivity:

• ผู้วิจัยเลือกใช้ ความไว 50 cm/360° ซึ่งถือว่าเป็นระดับ “เมาส์ช้า” (Low Sensitivity) โดยมีเหตุผลหลักดังนี้:

1. ข้อจำกัดของระบบควบคุมความเร็ว เนื่องจากมอเตอร์ที่ใช้เป็นรุ่นที่มีอัตราทดเกียร์ต่ำ (1:48) ทำให้มีแรงบิดต่ำและไม่สามารถเบรกหรือควบคุมความเร็วได้แม่นยำเท่าที่ควร โดยเฉพาะเมื่อมีการสั่งหยุดกระทันหัน
2. ความแม่นยำของการเคลื่อนที่ที่ดีกว่าในความเร็วต่ำ จากการทดสอบเบื้องต้นพบว่า เมื่อหุ่นยนต์วิ่งเร็ว (เช่นจำลองเมาส์เร็วหรือใช้เซนส์ต่ำ เช่น 20–33 cm/360°) จะเกิดอาการ overshoot หรือเล็งพลาดบ่อยครั้ง แต่หากใช้ความเร็วที่ต่ำลง หุ่นยนต์สามารถควบคุมตำแหน่งได้แม่นยำกว่ามาก
3. ทดลองใช้งานจริงแล้วพบว่าเมาส์เร็วไม่เวิร์ค ในขั้นตอนก่อนหน้า ผู้วิจัยเคยทดลองตั้งค่าความไวต่ำ (เมาส์เร็ว) แต่พบว่าไม่สามารถควบคุมได้ดี จึงตัดสินใจกลับมาใช้เมาส์ช้า

• ด้วยเหตุนี้จึงเลือกใช้ค่า 50 cm/360° ซึ่งเป็นค่า compromise ระหว่างความแม่นยำและระยะทางการเล็งที่ไม่ไกลเกินไป

ขั้นตอนการปรับจูน (PID Tuning Procedure)

เนื่องจากระบบควบคุมของหุ่นยนต์ไม่มี feedback encoder ทำให้ไม่สามารถวัดค่าความเร็วหรือค่าความแม่นยำของการเล็งได้โดยตรงในเชิงปริมาณ อีกทั้ง Kovaak's Aim Trainer ไม่อนุญาตให้ดึงข้อมูลการเคลื่อนไหวหรือผลลัพธ์จาก Custom Scenarios ได้โดยตรง (เช่น ไม่มี export logs หรือ telemetry) ดังนั้นผู้วิจัยจึงเลือกใช้แนวทางการจูน PID ด้วย “การสังเกตด้วยสายตา” (manual visual-based tuning) แทน

หมายเหตุ: หากผู้วิจัยมีความชำนาญสูงในด้านการสร้าง Custom Scenarios จะสามารถทำการสร้างระบบเก็บค่าได้ แต่ในโครงการนี้จะใช้สายตาเป็นหลักในการประเมินผลลัพธ์

วิธีการปรับจูน

1. ตั้งค่าเริ่มต้น:
  - เริ่มจาก Kp ≠ 0, Ki = 0, Kd = 0
  - จุดประสงค์คือเพื่อสังเกตการตอบสนองเบื้องต้นของระบบเมื่อมี error
2. ทดสอบกับเป้านิ่ง:
  - ทดสอบใน Custom Scenario ที่มีเป้าแบบคงที่ (Static Target) เพื่อประเมินว่า PID มีการทำงานเบื้องต้นที่เสถียรหรือไม่
3. ปรับ Kp ให้เหมาะสม:
  - เพิ่ม Kp ทีละน้อย
  - เป้าหมายคือให้หุ่นยนต์เคลื่อนที่เข้าใกล้เป้าหมายอย่างมั่นคง โดยไม่ oscillate ไปมา
4. เพิ่ม Kd เพื่อลด Overshoot:
  - หากหุ่นยนต์พุ่งเกินเป้าบ่อยครั้ง → ให้เพิ่มค่า Kd เพื่อช่วยลดอัตราเปลี่ยนแปลง
  - สังเกตการ "ชะลอตัวก่อนถึงเป้า" ว่าดีขึ้นหรือไม่
5. เพิ่ม Ki หากมี Steady-State Error:
  - หากหุ่นยนต์เคลื่อนใกล้เป้าหมายแล้วหยุดก่อนถึงเป้า หรือไม่สามารถเล็งตรงเป้ากลางจอได้ → อาจเป็นเพราะมีค่า error สะสมเล็ก ๆ ตลอดเวลา
  - การเพิ่ม Ki จะช่วย “ชดเชย” error สะสมเหล่านี้
6. เพิ่มความเร็วอย่างค่อยเป็นค่อยไป:
  - ทดสอบกับ Scenario ที่เป้าหมายเคลื่อนไหวเร็วขึ้นเรื่อย ๆ เพื่อจำลองการใช้งานจริง

ปัญหาที่พบจากการจูนด้วยสายตา

แม้ว่าการปรับจูนด้วยการสังเกตพฤติกรรมจะใช้งานได้จริง แต่เมื่อทดลองจริงกลับพบข้อจำกัดหลายประการ เช่น:

- พื้นผิวที่หุ่นยนต์เคลื่อนที่มีความลื่น ทำให้ braking จาก Kd ไม่เสถียร
- มอเตอร์มี Torque ต่ำ แม้ปรับค่า P สูงก็ยังไม่สามารถเคลื่อนเข้าจุดศูนย์กลางได้ดี
- ยากต่อการวัดผลจริง เช่น ความเร็วของการเล็ง, ระยะ overshoot, การนิ่งของ pointer

แนวทางแก้ไข

เพื่อให้การปรับจูนแม่นยำขึ้น และสามารถ "วิเคราะห์ผล" ได้ในเชิงวิศวกรรม ผู้วิจัยจึงเขียน ระบบบันทึกข้อมูล (Data Logger) เพิ่มเติมในโค้ด โดยจะเก็บค่า dx, dy, mode ในแต่ละเฟรม แล้วสามารถนำข้อมูลเหล่านี้ไปแสดงผลในรูปแบบกราฟเพื่อวิเคราะห์ภายหลัง

โค้ดที่สำคัญในการบันทึกข้อมูล

ส่วนที่ 1: logger.py — ใช้สำหรับบันทึกข้อมูลระหว่างการทำงาน

โค้ดนี้จะถูกรวมใน main loop โดยเรียก logger.log(dx, dy, mode) เพื่อเก็บค่าทุกเฟรม

ส่วนที่ 2: plotter.py — สำหรับแสดงผลข้อมูลที่เก็บในรูปกราฟ

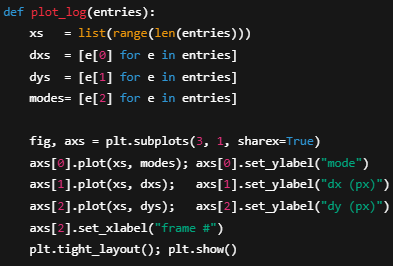
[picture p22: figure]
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

ผลลัพธ์ของกราฟนี้จะช่วยให้เห็นพฤติกรรมของระบบ PID ได้ชัดเจนขึ้น เช่น:

- มี overshoot หรือไม่ (จากกราฟ dx, dy)
- เคลื่อนที่ได้รวดเร็วพอหรือไม่
- มี jitter หลังเข้าเป้าหรือเปล่า

สรุป

- ปัญหาเรื่องพื้นผิวลื่น มอเตอร์ torque ต่ำ และไม่มี feedback encoder ทำให้ระบบ "สังเกตด้วยสายตา" อย่างเดียวไม่เพียงพอ
- การเพิ่มระบบ Logging ทำให้สามารถใช้วิธี "Data-Driven Tuning" ได้ → นำไปสู่การปรับ PID แบบเป็นระบบมากขึ้น
- ช่วยลดอคติจากการมองด้วยตา → ปรับค่าตามข้อมูลจริง → วิเคราะห์พฤติกรรมของระบบในแต่ละแกนได้ชัดเจน

การตั้งค่าโปรแกรมหลังการจูน

หลังจากทำการพัฒนาและเสริมฟังก์ชันระบบบันทึกข้อมูล (Data Logger) ลงในตัวหุ่นยนต์ ผู้วิจัยได้ดำเนินการจูนค่า PID เพื่อให้เหมาะสมกับลักษณะการเคลื่อนที่ในระบบจริง โดยใช้กรณีทดสอบจาก Sandbox Scenario ที่พัฒนาขึ้นเฉพาะสำหรับการจูน และจำลองสภาวะการทำงานใกล้เคียงกับเกมจริง (Kovaak) ที่ตั้งค่าความเร็วไว้ที่ประมาณ 70% ของความเร็วปกติ

ค่าพารามิเตอร์ PID ที่ได้จากการจูน มีดังนี้:

KP_X = 0.18 KI_X = 0.5 KD_X = 15.0

KP_Y = 0.13 KI_Y = 0.3 KD_Y = 7.0

โดยใช้ข้อมูลเฉพาะช่วง mode = 1 ซึ่งเป็นช่วงที่ระบบเข้าสู่การควบคุม PID มาทำการวิเคราะห์พฤติกรรมของระบบหุ่นยนต์ผ่านค่าความคลาดเคลื่อนในแกน X และ Y (dx, dy) ดังแสดงในกราฟด้านล่าง

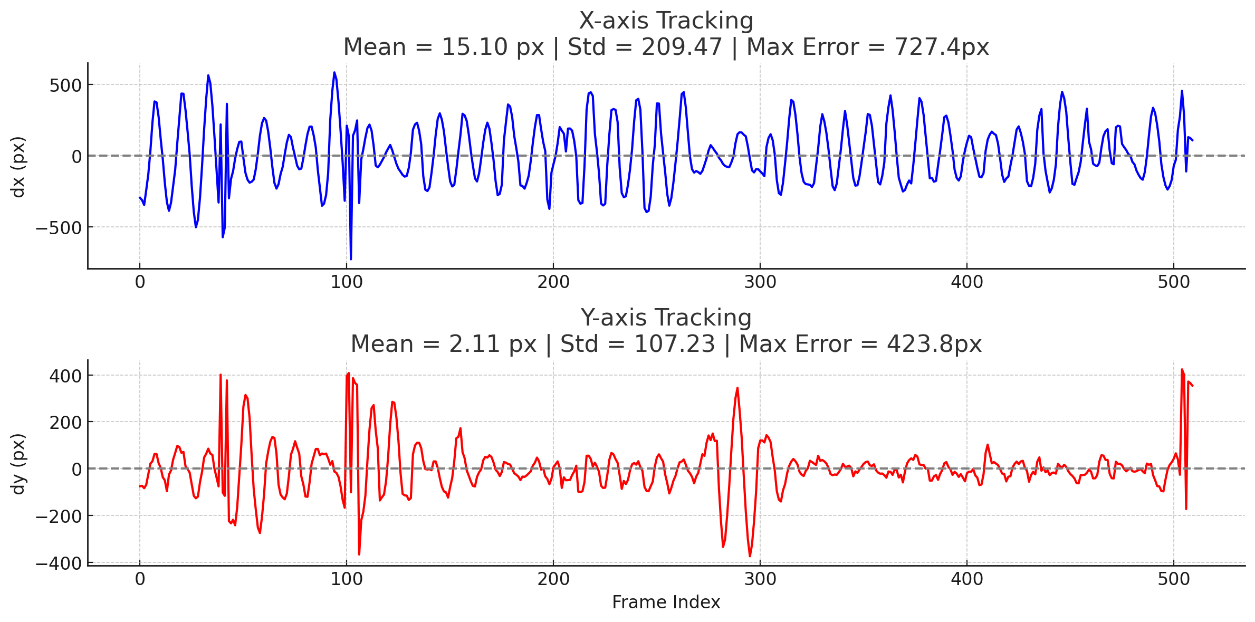
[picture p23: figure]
รูปภาพประกอบด้วย ข้อความ, ตัวอักษร, ไลน์, ภาพหน้าจอ เนื้อหาที่สร้างโดย AI อาจไม่ถูกต้อง

วิเคราะห์ผลจากข้อมูลจริง

สถิติของค่าความคลาดเคลื่อนในแกน X และ Y จากกราฟ (mode 1):

- X-axis Tracking
  - Mean Error = 11.36 px
  - Standard Deviation = 181.74 px
  - Max Error = 727.4 px
- Y-axis Tracking
  - Mean Error = 1.58 px
  - Standard Deviation = 92.98 px
  - Max Error = 423.8 px

จากค่าเฉลี่ยพบว่าระบบมีแนวโน้มเคลื่อนเข้าเป้าได้ใกล้ศูนย์โดยรวม แต่ยังมี ค่าความเบี่ยงเบนมาตรฐานสูง (Std) และมี ค่าความคลาดเคลื่อนสูงสุด (Max Error) จำนวนมากในบางเฟรม ซึ่งบ่งชี้ว่าเกิดอาการ overshoot และ jitter หลายจุด โดยเฉพาะช่วงต้นการเคลื่อนที่หรือเมื่อต้องเปลี่ยนทิศทางอย่างรวดเร็ว

วิเคราะห์

- ลักษณะการควบคุม: ระบบยังแสดงให้เห็นว่ามีอาการ overshoot ค่อนข้างบ่อยโดยเฉพาะในแกน X ซึ่งมีค่าความคลาดเคลื่อนสูงสุดถึง 727.4 px แสดงว่าแม้ค่าความเฉลี่ยจะอยู่ใกล้ศูนย์ แต่ความไม่เสถียรในการควบคุมยังมีอยู่มากในสภาพจริง
- ข้อจำกัดจากมอเตอร์: มอเตอร์ที่ใช้เป็นรุ่นราคาถูก (16 บาท/ตัว) แบบ Yellow TT 1:48 ซึ่งมีแรงบิดต่ำและอัตราทดเกียร์น้อย ทำให้ยากในการควบคุมที่ความเร็วต่ำ และเมื่อความเร็วรอบต่ำมาก อาจไม่เพียงพอในการเอาชนะแรงเสียดทานเริ่มต้นหรือหยุดการเคลื่อนที่ได้ทันท่วงที ส่งผลให้มี overshoot และ jitter ในระบบ
- พื้นผิวที่ลื่น: หุ่นยนต์ถูกวางทดสอบบนพื้นกระเบื้องที่มีแรงเสียดทานต่ำ (slippery surface) ทำให้ระบบมี braking distance สูงกว่าปกติ กล่าวคือเมื่อสั่งหยุดหรือเปลี่ยนทิศ มอเตอร์อาจสั่งหยุดแล้ว แต่ตัวหุ่นยังลื่นไถลต่อด้วยแรงเฉื่อย
- ข้อจำกัดเชิงกลไกและการออกแบบ:
  - ไม่มี feedback encoder → ไม่สามารถปรับ PID จากค่าความเร็วจริงได้
  - ระบบต้องใช้ความเร็วมากขึ้นเพื่อให้มอเตอร์มีแรงพอ → ทำให้ต้องเคลื่อนที่ในระยะที่กว้างขึ้น
  - ค่าความไวของเมาส์ (low sensitivity) ถูกตั้งไว้ต่ำ เพื่อให้เหมาะกับระยะเคลื่อนที่ที่มากขึ้นของหุ่นยนต์ แต่ยิ่งลด sens ก็ยิ่งต้องขยับไกล จึงเป็นวงจรที่เกี่ยวข้องกันทั้งหมด

สรุปและแนวโน้มการปรับปรุง

- การเสริมระบบ Logging ทำให้สามารถใช้แนวทาง Data-Driven PID Tuning ได้จริง และสามารถอธิบายพฤติกรรมของระบบได้ละเอียดมากกว่าการดูด้วยสายตา
- ปัญหาหลักที่พบยังคงเป็น แรงเสียดทานต่ำ, มอเตอร์แรงบิดน้อย, และไม่มีระบบ feedback
- แนวทางพัฒนาในอนาคตอาจพิจารณา:
  - เปลี่ยนเป็นมอเตอร์เกียร์ทดสูงขึ้น (เช่น 1:100 หรือมากกว่า)
  - เสริม encoder สำหรับ feedback
  - ใช้พื้นทดสอบที่มีแรงเสียดทานสูงขึ้น หรือใช้ยางรองล้อ
  - ปรับ logic PID เพื่อเพิ่ม anti-windup หรือ deadband
- แม้ว่าค่าพารามิเตอร์ PID ที่ได้ในครั้งนี้ ยังไม่ถือว่าเป็นค่าที่ดีที่สุดในเชิงทฤษฎี แต่จากผลการทดสอบสามารถกล่าวได้ว่า “เพียงพอต่อการใช้งานในเบื้องต้น” และสร้างผลลัพธ์ที่มีเสถียรภาพในระดับหนึ่ง ซึ่งเหมาะสมต่อการใช้เป็นจุดเริ่มต้น (baseline) สำหรับการทดลองหรือปรับแต่งเพิ่มเติมในอนาคต

### 3.6.6 สรุปการผสานระบบและการทำงานของระบบจริง (Final Integration and System Completion Summary)

หลังจากดำเนินการในทุกโมดูลตั้งแต่การสร้าง Dataset, การฝึกโมเดล, การออกแบบและสร้างฮาร์ดแวร์, รวมถึงการพัฒนา Software Interface และ PID Controller แล้ว ระบบ Aimbot ทางกายภาพ (Physical Aimbot System) ได้รับการผสานรวมอย่างสมบูรณ์ในเชิงฟังก์ชัน โดยสามารถจับภาพหน้าจอเกม Kovaak, ประมวลผลเป้าหมาย, คำนวณ Inverse Kinematics, และควบคุมการเคลื่อนที่ของเมาส์ผ่านหุ่นยนต์ที่ติดตั้งล้อ Mecanum ได้อย่างต่อเนื่องแบบเรียลไทม์

ภาพรวมของระบบที่ใช้งานจริง

ระบบถูกปรับปรุงจากแนวคิดเริ่มต้น โดยตัดโมดูล Bluetooth shooting จาก ESP32 ออก และย้ายการคำนวณทั้งหมด—including PID และ Inverse Kinematics—มาอยู่บนฝั่ง PC เพื่อเพิ่มความยืดหยุ่นในการพัฒนาและประหยัดเวลาในการทดสอบ โดยระบบมีองค์ประกอบหลักดังนี้:

1. Screen Capture + YOLO Detection
  - ใช้ Python + mss + YOLOv5 เพื่อจับภาพจากหน้าจอเกมและตรวจจับตำแหน่งเป้าหมายแบบเรียลไทม์
  - แสดงผลผ่านหน้าต่าง Aimbot View ด้วย cv2.imshow() พร้อม Overlay ข้อมูลเป้า
2. PID Controller และการ Mapping ทิศทาง
  - คำนวณความคลาดเคลื่อนตำแหน่ง (dx, dy) ของเป้าหมายจากจุดศูนย์กลางหน้าจอ
  - ปรับค่า Error เข้าสู่ PID controller ในแกน X/Y โดยแยกกันอิสระ
  - คำนวณความเร็ว vx และ vy ที่ต้องการในแนวแกนทั้งสอง
3. Inverse Kinematics & Normalization
  - แปลง vx, vy เป็นค่าความเร็วล้อทั้ง 4 ตามทฤษฎีล้อ Mecanum (ไม่มีการหมุนตัว – ω = 0)
  - Normalize ความเร็วให้ไม่เกิน 100% พร้อมปรับทิศทางล้อ (ตาม wiring จริงใน config.py)
4. Serial Transmission to ESP32
  - ส่งความเร็ว 4 ล้อในรูปแบบ string เช่น "23,-45,30,-40\n" ผ่าน PySerial
  - ESP32 รับข้อมูล → แปลงเป็น PWM โดยใช้การ Mapping ที่เคยทดลองจาก minspeedtest.py
  - สั่ง PWM ไปยัง DRV8833 Motor Driver ทุก 10 ms
5. Motion Execution
  - ล้อขับเคลื่อนหุ่นยนต์ไปยังเป้าหมายแบบละเอียด โดยใช้ค่าความเร็วที่ถูกจูนด้วย PID
  - ระบบสามารถหยุดเล็งเมื่อเป้าเข้าสู่ “On-Target Zone” และคลิกผ่าน pynput.mouse

การสรุปโมดูลทั้งหมดจากฝั่ง PC

โมดูล | ไฟล์ | หน้าที่
Detection & Aimbot View | main.py | จับภาพหน้าจอและแสดงผล Overlay
Object Detection | detect.py | โหลดและรัน YOLOv5
PID Control | pid.py, wheel_control.py | คำนวณ vx/vy จาก error และ PID
Inverse Kinematics | kinematics.py | คำนวณค่าความเร็วของล้อจาก vx/vy
Serial Communication | serial_sender.py | ส่งค่า speed ไปยัง ESP32
Logging + Plotting | logger.py, plotter.py | เก็บข้อมูล dx/dy/mode และแสดงกราฟวิเคราะห์ PID

โมดูลฝั่ง ESP32 (main.cpp)

ESP32 ถูกตั้งโปรแกรมให้ทำหน้าที่เฉพาะ:

- อ่านค่าความเร็วจาก Serial (–100 ถึง +100)
- แปลงความเร็วเป็น PWM ที่เหมาะกับมอเตอร์ (Deadzone < ±140)
- ควบคุมล้อ 4 ตัวผ่าน DRV8833 (ใช้ PWM ความถี่ 5 kHz, ความละเอียด 8-bit)
- ไม่ต้องคิด logic เพิ่มเติม → ลดภาระ MCU

การตั้งค่าทางไฟฟ้า:

- ความเร็ว Mapping เริ่มจาก ±1 = PWM 140 → ±100 = PWM 255
- ช่วยลดอาการ Deadzone และให้ระบบตอบสนองแม่นยำขึ้นในช่วงความเร็วต่ำ

สถานะปัจจุบันของระบบ

- ระบบสามารถเคลื่อนที่ตามเป้าหมายที่ตรวจจับได้อย่างต่อเนื่อง
- PID ได้รับการปรับจูนให้เหมาะสมสำหรับการติดตามเป้าหมายที่เคลื่อนที่เร็วระดับปานกลาง (นิยามโดย Scenario ใน Kovaak)
- รองรับการทำงานแบบเรียลไทม์ได้ในระดับที่ "เพียงพอ" สำหรับใช้งานเบื้องต้น
- ESP32 ควบคุมมอเตอร์ได้อย่างราบรื่นโดยไม่มี delay ที่รู้สึกได้
- มีระบบ Logging เพื่อตรวจสอบการทำงานย้อนหลังและวิเคราะห์ PID อย่างเป็นระบบ

ข้อเสนอแนะสำหรับรุ่นถัดไป

- ควรเพิ่ม Feedback เช่น Optical Encoder เพื่อตรวจสอบพฤติกรรมล้อจริง → จูน PID แบบ Closed-loop ได้
- อาจเปลี่ยนมอเตอร์เป็นแบบ Torque สูงหรือมี Gear Ratio ที่เหมาะสมขึ้น (เช่น 1:100)
- พัฒนา Interface ให้สามารถ “บันทึกและวิเคราะห์ผลอัตโนมัติ” จากเกม Kovaak ได้ โดยไม่ต้องพึ่งสายตา

# บทที่ 4 การทดลองและผลการทดลอง/วิจัย

ในการทดลองครั้งนี้ ผู้วิจัยได้แบ่งการทดลองออกเป็น 3 ส่วนหลักเพื่อให้ง่ายต่อการวิเคราะห์และปรับปรุงระบบ ได้แก่

- ส่วนที่ 1: การทดสอบซอฟต์แวร์ (Software Testing)
- ส่วนที่ 2: การทดสอบฮาร์ดแวร์ (Hardware Testing)
- ส่วนที่ 3: การทดสอบระบบรวม (Integrated System Testing)

## 4.1การทดสอบซอฟต์แวร์ (Software Testing)

### 4.1.1 การทดสอบความสามารถในการตรวจจับวัตถุจากวิดีโอ (Object Detection Performance)

วัตถุประสงค์ของการทดลอง

เพื่อประเมินความสามารถของโมเดล YOLOv5 ขนาดต่าง ๆ ในการตรวจจับวัตถุ (Robot) จากวิดีโอที่ได้จากโปรแกรมฝึกเล็ง Kovaak โดยใช้วิดีโอสถานการณ์ (Scenario) ที่มีความหลากหลาย เช่น เป้าหมายซ้อนกัน ความเร็วสูง หรือระยะใกล้กล้อง การทดลองนี้ช่วยให้สามารถเลือกโมเดลที่เหมาะสมกับงานระบบ Aimbot แบบเรียลไทม์ได้อย่างมีประสิทธิภาพ

ตัวแปรในการทดลอง

ประเภทตัวแปร | รายละเอียด
ตัวแปรต้น (Independent Variables) | โมเดลที่ใช้ (YOLOv5s_old, YOLOv5s_v2, YOLOv5m, YOLOv5l, YOLOv5x), ขนาดภาพ 640×640
ตัวแปรตาม (Dependent Variables) | อัตราการตรวจจับ (Detected Frames), ค่า Confidence เฉลี่ย, จำนวนวัตถุที่ตรวจพบ
ตัวแปรควบคุม (Controlled Variables) | Resolution: 1920×1080, FPS: 12, ความยาววิดีโอ: 10 วินาที, ใช้ skip_frames = 1

วิธีการทดลอง

1. การนับวัตถุด้วยตนเอง (Manual Counting):
  - ในการทดลองนี้ได้ใช้ Python (frame_count.py) ในการแสดงแต่ละเฟรมเพื่อทำการนับจำนวนวัตถุด้วยตนเอง (Manual Counting) เพื่อให้มั่นใจว่าข้อมูลที่ได้ถูกต้องที่สุด โดยสคริปต์จะสรุปผลออกมาเป็นจำนวนเฟรมทั้งหมดที่ตรวจพบวัตถุและจำนวนเฟรมที่ไม่พบวัตถุอย่างชัดเจน
  - ใช้เพื่อกำหนด baseline เปรียบเทียบกับผลลัพธ์ของโมเดล

โค้ดสำคัญ (frame_count.py):

ผู้วิจัยได้ทำการบันทึกวิดีโอจากโปรแกรม Kovaak ที่ความละเอียดระดับ Full HD (1920x1080) และอัตราเฟรม 12 fps โดยแต่ละ scenario จะมีความยาว 10 วินาที รวมทั้งหมด 5 scenarios ดังนี้

ชื่อ Scenario | รายละเอียด | จำนวนเฟรมทั้งหมด | ตรวจพบวัตถุ (เฟรม) | ไม่พบวัตถุ (เฟรม)
Close Fast Colosseum Robots No Shooting | Robot วิ่งรอบ ๆ ไม่มี Damage | 120 | 120 | 0
[N] CLS Click Robots | Robot วิ่งรอบ ๆ มี Damage | 119 | 119 | 0
RoboTS180 | Robot หลายตัววิ่งรอบ ๆ มี Damage | 119 | 322 | 3
Cata IC Fast Strafes Robot | Robot วิ่ง มี Damage, สภาพแวดล้อมต่างออกไป | 119 | 108 | 11
Close Fast Strafes Invincible OW Robot | Robot วิ่งใกล้มาก ไม่มี Damage | 120 | 120 | 0

2.การประเมินผลโมเดลแบบอัตโนมัติ (Automated Testing):

- หลังจากทำการนับด้วยตนเอง (Manual Counting) เสร็จแล้ว ผู้วิจัยได้ทดสอบโมเดลทั้ง 5 ขนาด (small_old, small_new, medium, large, x) โดยใช้สคริปต์ Python ที่พัฒนาขึ้นเพื่อวิเคราะห์ความสามารถของแต่ละโมเดลในการตรวจจับเป้าหมายจากวิดีโอจริงของโปรแกรม Kovaak
- โค้ดที่ใช้มีชื่อว่า modeltest.py ซึ่งทำหน้าที่โหลดวิดีโอจากแต่ละ Scenario และรันการตรวจจับแบบ frame-by-frame โดยวัดค่าดังต่อไปนี้

:

  - จำนวนเฟรมทั้งหมด
  - จำนวนเฟรมที่ตรวจจับได้
  - จำนวนวัตถุทั้งหมดที่ตรวจพบ
  - ค่า confidence เฉลี่ย

โค้ดสำคัญ (modeltest.py):

กำหนด CONF_THRESHOLD = 0.25 และ SKIP_FRAMES = 1 เพื่อความแม่นยำในการประเมิน

หลังจากทำการนับด้วยตนเอง (Manual Counting) เสร็จแล้ว ผู้วิจัยได้ทดสอบโมเดลทั้ง 5 ขนาด (small_old, small_new, medium, large, x) โดยใช้สคริปต์ Python ที่พัฒนาขึ้นเพื่อวิเคราะห์ความสามารถของแต่ละโมเดลในการตรวจจับเป้าหมายจากวิดีโอจริงของโปรแกรม Kovaak

โค้ดที่ใช้มีชื่อว่า modeltest.py ซึ่งทำหน้าที่โหลดวิดีโอจากแต่ละ Scenario และรันการตรวจจับแบบ frame-by-frame โดยวัดค่าดังต่อไปนี้:

- จำนวนเฟรมทั้งหมด
- จำนวนเฟรมที่ตรวจจับได้
- จำนวนเฟรมที่ไม่ตรวจจับ
- จำนวนวัตถุทั้งหมดที่ตรวจพบ (Total Detections)
- ค่าเฉลี่ย Confidence (Average Confidence Score)

สรุปผลการทดลอง

Scenario | small_old | small_new | medium | large | x
[N] CLS Click Robots | 87 / 119 (73.1%) | 88 / 119 (74.0%) | 111 / 119 (93.3%) | 119 / 119 (100.0%) | 119 / 119 (100.0%)
Cata IC Fast Strafes | 95 / 119 (79.8%) | 32 / 119 (26.9%) | 37 / 119 (31.1%) | 69 / 119 (58.0%) | 46 / 119 (38.7%)
Colosseum No Shooting | 72 / 120 (60.0%) | 111 / 120 (92.5%) | 118 / 120 (98.3%) | 118 / 120 (98.3%) | 119 / 120 (99.2%)
OW Robot (Close Fast) | 1 / 120 (0.8%) | 118 / 120 (98.3%) | 120 / 120 (100%) | 120 / 120 (100%) | 120 / 120 (100%)
RoboTS180 | 101 / 119 (84.9%) | 44 / 119 (37.0%) | 23 / 119 (19.3%) | 108 / 119 (90.8%) | 45 / 119 (37.8%)

ค่า Confidence (เฉลี่ย):

- small_old: 0.52
- small_new: 0.43
- medium: 0.47
- large: 0.57
- x: 0.54

วิเคราะห์ผลและสรุป (Analysis and Summary)

1. [N] CLS Click Robots
  - ทุกโมเดลสามารถตรวจจับได้ดี (≥ 73% → 100%) เนื่องจากเป้าหมายอยู่ในระยะชัดเจน ไม่มีการ overlap หรือความเร็วสูง
  - large และ x ทำได้ 100% แสดงถึงความเสถียรของโมเดลใหญ่ในงานที่มีลักษณะเป้าเด่น
2. Cata IC Fast Strafes Robot
  - small_old (79.8%) แสดงว่า generalize จาก dataset ได้ดีพอสมควร
  - small_new (26.9%) และ medium (31.1%) ตรวจจับได้น้อย สาเหตุจาก dataset v2 มีเงื่อนไขต่างออกไป (เช่น visual effects ของ damage, ความต่างของ background)
  - โมเดลใหญ่ (large: 58.0%, x: 38.7%) ดีกว่าเล็กน้อย แต่ยังมีปัญหาในสถานการณ์ที่เป้าหมายเคลื่อนไหวเร็วและมีการ overlap
3. Close Fast Colosseum Robots No Shooting
  - small_old ตรวจจับได้เพียง 60.0% คาดว่า background และมุมกล้องคล้ายฉากอื่นมากเกินไปจนทำให้โมเดลสับสน
  - หลังจากเพิ่ม augment และ dataset ในเวอร์ชันใหม่ (small_new → x) ทำให้ตรวจจับได้ ≥ 92.5%
4. Close Fast Strafes Invincible OW Robot
  - small_old ตรวจจับแทบไม่ได้ (0.8%) เนื่องจาก target อยู่ใกล้กล้องเกินไปจนหลุดจาก bounding box
  - โมเดลใหม่ทุกตัว (small_new, medium, large, x) ตรวจจับได้ดีมาก (≥ 98%) หลังจาก augment และเพิ่ม data แบบ close-up view
5. RoboTS180
  - small_old ทำได้ 84.9% ในกรณีที่มี multiple targets แต่บางครั้งมีเฟรมที่ confidence สูงค้าง
  - small_new, medium, x ตรวจจับได้น้อยมาก (19–37%) เนื่องจากการ overlap กันของเป้าหมายทำให้โมเดลเสีย recall
  - large ทำได้ดีที่สุด (90.8%) เนื่องจาก model capacity สูงพอที่จะแยก object ที่ซ้อนกันได้

สรุปเชิงเทคนิค

- โมเดลขนาดใหญ่ (large, x) มีความสามารถในการจัดการกับฉากที่ซับซ้อน เป้าหมายซ้อนกัน หรือมีเอฟเฟกต์พิเศษได้ดีกว่า เนื่องจากมี parameter มากและ receptive field ที่กว้าง
- small_new มี performance ดีขึ้นจาก small_old ในหลายกรณี แสดงว่าการเพิ่ม dataset และ augment ช่วยให้โมเดล generalize ได้ดีขึ้น
- medium มีอาการ overfit กับ training set และมี recall ต่ำในบางฉาก ทำให้ตรวจจับไม่ได้ดีนักใน real-world scene
- ความแตกต่างระหว่าง small_old กับ small_new ยังแสดงให้เห็นว่า dataset และการ augment มีผลอย่างมากต่อ performance ของโมเดล

ข้อสังเกตจากการทดลอง

- ผลจากวิดีโอจริงแสดงให้เห็นว่า "ความแม่นยำในการวัดจาก validation set อย่างเดียวไม่เพียงพอ" เพราะบางโมเดลที่มี mAP สูง กลับมี performance ต่ำในฉากจริง
- ความสามารถในการ detect จากวิดีโอจึงควรถูกใช้ร่วมกับการประเมิน latency และความเร็ว (ดูหัวข้อ 4.1.2–4.1.3) เพื่อประกอบการตัดสินใจเลือกโมเดล

### 4.1.2 การทดสอบ Latency บน RTX 3060 (Inference Latency Testing)

วัตถุประสงค์

เพื่อวัดความหน่วง (Latency) ของการประมวลผลภาพต่อเฟรม (Inference Time) ของโมเดล YOLOv5 ขนาดต่าง ๆ โดยรันบนเครื่อง ASUS TUF A15 (RTX 3060 Laptop Max-Q) ด้วยสภาพแวดล้อม Python แบบเดียวกัน เพื่อเปรียบเทียบว่าขนาดของโมเดลมีผลต่อระยะเวลาประมวลผลเพียงใด และประเมินว่า latency ดังกล่าวอยู่ในระดับที่เหมาะสมสำหรับการใช้งานแบบเรียลไทม์หรือไม่

ตัวแปรในการทดลอง

- ตัวแปรต้น (Independent Variable):
  - ขนาดของโมเดล YOLOv5 ได้แก่ small_old, small_new, medium, large, x
- ตัวแปรตาม (Dependent Variable):
  - ค่า latency ที่วัดได้ (ms/frame) ได้แก่ mean, min, max
- ตัวแปรควบคุม (Controlled Variables):
  - ความละเอียดวิดีโอ: 1920×1080 @ 12 fps
  - สภาพแวดล้อม: Python 3.8, PyTorch 2.1, CUDA 12.1
  - จำนวน frame ที่ใช้ต่อการวัด: ~120 เฟรมต่อวิดีโอ
  - ค่าคงที่ confidence threshold: 0.25
  - อุปกรณ์ในการใช้รันโมเดล Asus TUF A15

ขั้นตอนการทดลอง

1. สคริปต์ modeltest_latency.py จะทำการโหลดโมเดล YOLOv5 แต่ละขนาดด้วย confidence คงที่ และทำการวิเคราะห์วิดีโอ 5 ฉากจากโปรแกรม Kovaak โดยใช้ OpenCV
2. สำหรับแต่ละเฟรมในวิดีโอ จะจับเวลาระหว่าง t0 = time.time() และ t1 = time.time() ก่อน–หลังเรียกใช้งานโมเดล
3. สรุปค่า latency แบบเฉลี่ย (mean), น้อยสุด (min), และมากสุด (max) สำหรับแต่ละโมเดล–วิดีโอ

ตัวอย่างโค้ดสำคัญจาก modeltest_latency.py

ผลการทดลอง (ms/frame)

Model | Scenario 1 | Scenario 2 | Scenario 3 | Scenario 4 | Scenario 5 | Mean | Min | Max
small_old | 16.8 | 15.1 | 15.8 | 14.0 | 15.9 | 15.5 | 11.6 | 185.7¹
small_new | 15.7 | 14.8 | 16.2 | 16.1 | 15.2 | 15.6 | 11.5 | 34.0
medium | 19.7 | 17.7 | 19.5 | 19.4 | 18.0 | 18.9 | 14.0 | 90.5
large | 23.8 | 22.1 | 22.3 | 23.5 | 23.1 | 23.0 | 17.5 | 92.5
x | 32.2 | 29.9 | 30.9 | 31.3 | 29.5 | 30.8 | 26.0 | 109.5

¹ ค่า Max ของ small_old เกิดจาก spike ชั่วคราวของ GPU background process

การวิเคราะห์ผล

- small_old vs. small_new: แม้ latency ใกล้เคียงกัน (≈15.5 ms) แต่ small_new มี Max latency ที่นิ่งกว่า (34 ms vs. 185 ms) แสดงให้เห็นว่า dataset ใหม่และการ train ที่เหมาะสมช่วยลด outlier
- medium: มีค่า latency เฉลี่ย ~18.9 ms (≈ 53 FPS) ซึ่งยังสามารถประมวลผลได้รวดเร็วพอสมควร แต่มี Max spike สูงในบางเฟรมที่มี object ซับซ้อน
- large: latency เฉลี่ย ~23.0 ms (≈ 43 FPS) มีความเสถียรดี แต่เริ่มส่งผลต่อความลื่นไหลในการติดตามเป้าหมายที่เคลื่อนไหวเร็ว
- x: latency เฉลี่ย ~30.8 ms (≈ 32 FPS) ถือว่าต่ำกว่าเกณฑ์ที่เหมาะสมสำหรับเกม FPS ที่ต้องการ ≥60 FPS โดยมี latency สูงสุดถึง 109.5 ms ในบางเฟรม
- สรุปอัตราเฟรม (คำนวณจาก Mean Latency):

Model | Mean Latency (ms) | Approx FPS (1 / latency)
small_old | 15.5 | ~64 FPS
small_new | 15.6 | ~64 FPS
medium | 18.9 | ~53 FPS
large | 23.0 | ~43 FPS
x | 30.8 | ~32 FPS

ข้อสังเกตเพิ่มเติม

- ค่า latency ต่ำสุด (Min) ของทุกโมเดลอยู่ในช่วง ~11–14 ms ซึ่งสะท้อนว่า GPU สามารถประมวลผลได้เร็วมากในกรณีที่ภาพไม่ซับซ้อน
- ค่า latency สูงสุด (Max) มักเกิดเมื่อมี object ซ้อนกันหลายตัว (เช่นใน Scenario RoboTS180) ซึ่งเป็นภาระที่หนักต่อโมเดล

สรุป

โมเดล YOLOv5s (new) มีค่า latency ต่ำที่สุดในการทดสอบ โดยสามารถรันได้ที่ ~64 FPS บน RTX 3060 (Laptop Max-Q) ซึ่งมากเพียงพอสำหรับการประมวลผลแบบเฟรมต่อเฟรม โดยเฉพาะสำหรับระบบที่ต้องการตอบสนองรวดเร็ว เช่น การเล็งเป้าหมายในเกม

### 4.1.3 การทดสอบผลกระทบต่ออัตราเฟรม-เรตของเกม (In-game FPS Impact Test)

จุดประสงค์ของการทดลอง

เพื่อศึกษาว่าโมเดล YOLOv5 ขนาดต่าง ๆ มีผลกระทบต่ออัตราเฟรมเรต (FPS) ของเกมมากน้อยเพียงใด เมื่อใช้งานร่วมกับเกม Kovaak แบบเรียลไทม์ โดยเฉพาะเมื่อโมเดลรันพร้อมกันกับเกมบนเครื่อง ASUS TUF A15 (RTX 3060 Laptop, 6GB VRAM)

ตัวแปรของการทดลอง

- ตัวแปรต้น (Independent Variable): ขนาดของโมเดล YOLOv5 ที่ใช้งาน (small_old, small_new, medium, large, x)
- ตัวแปรควบคุม (Controlled Variables):
  - ความละเอียดหน้าจอ: 1920 × 1080 (Full HD)
  - V-sync: ปิด (Off)
  - Scenario ที่ใช้: แบบเดียวกันทุกครั้ง
  - เฟรมเรตก่อนรันโมเดล (baseline): 270–290 FPS
  - โปรแกรมตรวจจับที่ใช้: Python + YOLOv5 + OpenCV
  - ค่า Confidence: 0.25
  - คำสั่งภาพ: 640 × 640 (IMGSZ)
- ตัวแปรตาม (Dependent Variable):
  - ค่า FPS ของเกมขณะรัน YOLO แต่ละรุ่น
  - ความลื่นไหลของหน้าจอ Aimbot View
  - ความสามารถในการตรวจจับเป้าหมายแบบต่อเนื่อง

วิธีการทดสอบ

1. ใช้สคริปต์ modeltest_runwithgame.py โหลดโมเดล YOLOv5 ขนาดต่าง ๆ
2. ดึงภาพหน้าจอจากเกม Kovaak แบบเรียลไทม์ด้วย mss และส่งให้โมเดลตรวจจับ
3. รันการตรวจจับบนเฟรมจากเกมจริง โดยใช้ cv2.imshow() แสดงผลพร้อม overlay
4. ตรวจวัด ค่า FPS จากตัววัดของเกม และ สังเกตความลื่นของหน้าต่าง Aimbot View
5. วัดค่า GFLOPs ของแต่ละโมเดลจาก model.summary() เพื่ออ้างอิงภาระคำนวณ

ตัวอย่างโค้ดสำคัญ

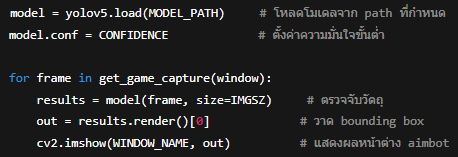
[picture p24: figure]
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

ตารางผลการทดสอบ

Model | GFLOPs | FPS (Avg.) | สังเกตใน Aimbot View
YOLOv5s (old) | 15.8 | 274 | ตรวจจับกระตุกบ้าง, หลุดเป้าเมื่อเร็ว
YOLOv5s (v2) | 15.8 | 267 | ตรวจจับนิ่งขึ้น แต่มีอาการ “ขาดช่วง” บ้าง
YOLOv5m | 48.2 | 243 | ตรวจจับนิ่งและเสถียรกว่า small
YOLOv5l | 108.2 | 252 | ตรวจได้แม่นมาก และนิ่งตลอด
YOLOv5x | 204.6 | 247 | ตรวจแม่นเทียบเท่า large, Aimbot View เริ่มช้าลงนิดหน่อย

*FPS baseline (ไม่เปิดโมเดล): ~270–290 FPS
*Aimbot View = หน้าต่างที่ render YOLO overlay แยกต่างหากจากเกมจริง

วิเคราะห์ผล

- FPS ของเกมแทบไม่ลดลงมากนัก เมื่อเพิ่มขนาดโมเดล YOLO แม้ GFLOPs สูงขึ้นมาก (YOLOv5x ใช้ 204 GFLOPs แต่ยังคง FPS ~247)
- แสดงว่า RTX 3060 Laptop ยังมีทรัพยากรเพียงพอในการรันเกมและโมเดลพร้อมกัน
- ส่วนที่เห็นผลต่างชัดที่สุดคือ Aimbot View (cv2.imshow) ที่มีอาการ “ตรวจไม่ต่อเนื่อง” หรือกระตุก Framerate จอ Aimbot view ลดลงอย่างเห็นได้ชัดเจน เมื่อใช้โมเดลขนาดใหญ่
- อาการนี้อาจเกิดจากการ render overlay ที่มากขึ้น หรือ latency ที่สูงขึ้นในระดับเฟรม (เช่นจาก 15ms → 30ms) แม้ว่า FPS ในเกมจะยังคงสูง

ข้อสังเกตเพิ่มเติม

- ในมุมมองของผู้เล่น (Game View) เกมยังคงลื่น (~240 FPS ขึ้นไปทุกโมเดล)
- แต่ใน Aimbot View ที่ใช้สำหรับตรวจจับกลับ “รู้สึกช้าลง” ตามขนาดของโมเดล
- ซึ่งอาจส่งผลต่อ คุณภาพการตรวจจับ เมื่อทำงานร่วมกับระบบ PID (อาจ tune ได้ยากขึ้น)

### 4.1.4 สรุปผลการทดสอบเบื้องต้น (Overall Test Summary)

หลังจากดำเนินการทดสอบในหัวข้อ 4.1.1 – 4.1.3 ซึ่งประกอบด้วย

- การประเมินความสามารถของโมเดลในการตรวจจับเป้าหมายจากวิดีโอ (Object Detection Performance)
- การทดสอบเวลาแฝงในการประมวลผล (Inference Latency)
- การทดสอบผลกระทบของโมเดลต่ออัตราเฟรมของเกม (In-game FPS Impact)

สามารถสรุปผลและวิเคราะห์เชิงวิศวกรรมได้ดังนี้:

1) ความสามารถในการตรวจจับวัตถุ (Detection Accuracy – จากหัวข้อ 4.1.1)

- โมเดลขนาดใหญ่ (YOLOv5l, YOLOv5x) แสดงศักยภาพสูงในการตรวจจับเป้าหมายในฉากที่มีความซับซ้อน เช่น เป้าหมายซ้อนกัน (overlap) หรือเคลื่อนที่รวดเร็ว (fast strafe) โดยให้ค่า Detection Rate สูงใกล้เคียง 100%
- โมเดลขนาดเล็ก (YOLOv5s_old, YOLOv5s_new) มีข้อดีด้านความเร็วและขนาดโมเดล แต่มีอัตราการพลาด (missed detection) ที่สูงขึ้นในฉากที่มีลักษณะซับซ้อนหรือเปลี่ยนแปลงสูง เช่น ภาพมุมใกล้ หรือ background เปลี่ยนบ่อย
- YOLOv5s_new แสดงประสิทธิภาพดีขึ้นอย่างชัดเจนจากการปรับปรุง dataset และ augment เพิ่มเติม เมื่อเทียบกับ YOLOv5s_old

2) เวลาแฝงในการประมวลผล (Latency – จากหัวข้อ 4.1.2)

- ค่าความหน่วงเฉลี่ย (mean inference time) เพิ่มขึ้นตามขนาดของโมเดล อย่างชัดเจน
- ตัวอย่าง:
  - YOLOv5s_new: ~15.6 ms/frame (~64 FPS)
  - YOLOv5x: ~30.8 ms/frame (~32 FPS)
- ค่า latency ≤ 20 ms ถือว่าอยู่ในระดับที่สามารถใช้งานกับระบบ real-time ได้ (เช่น ระบบช่วยเล็ง)
- เครื่องที่ใช้ในการทดสอบ (RTX 3060 Laptop Max-Q, 6GB VRAM) สามารถประมวลผลได้ดีถึงระดับ YOLOv5m โดยไม่เกิดปัญหา delay

3) ผลกระทบต่อการเล่นเกม (In-Game FPS Impact – จากหัวข้อ 4.1.3)

- เฟรมเรตของตัวเกมจริง (Kovaak) แทบไม่ลดลงอย่างมีนัยสำคัญ แม้ใช้โมเดลที่มี GFLOPs สูง เช่น YOLOv5x (~204 GFLOPs)
- แต่ Aimbot View (หน้าต่างแสดงผลการตรวจจับ) มีความลื่นลดลงชัดเจน ตามขนาดของโมเดล เนื่องจากการ render overlay และ copy frame มีภาระมากขึ้น
- สาเหตุหลักของอาการ “ไม่ต่อเนื่อง” อาจเกิดจาก latency ที่เพิ่มขึ้นต่อเฟรม เมื่อใช้โมเดลขนาดใหญ่

ข้อสรุป

- ไม่สามารถสรุปขนาดโมเดลที่เหมาะสมได้ในขั้นตอนนี้ เนื่องจากแต่ละขนาดมี trade-off ที่แตกต่างกัน:
  - ขนาดใหญ่ → ความแม่นยำสูง แต่ latency และ resource เพิ่มขึ้น
  - ขนาดเล็ก → เร็วและเบา แต่พลาดง่ายในบาง scenario
- จึงจำเป็นต้องนำผลการทดสอบจากระบบจริง (Integration Testing) มาร่วมพิจารณาในบทถัดไป (หัวข้อ 4.2 และบทที่ 5)

ค่าความมั่นใจที่เหมาะสม (Optimal Confidence Threshold)

จากการทดลองในทุกหัวข้อ พบว่า
ค่าความมั่นใจ (confidence threshold) ที่เหมาะสมคือ 0.25
เนื่องจากให้ผลลัพธ์ที่สมดุลในทุกมิติ ได้แก่:

- ให้ค่า Precision และ Recall อยู่ในจุดสมดุลที่ดี
- ไม่สร้างภาระกับ GPU เกินไป (ความเร็วคงที่)
- ไม่เพิ่ม latency อย่างมีนัยสำคัญ
- ไม่เกิด false positive หรือ false negative มากเกินไป

ดังนั้น ค่า threshold นี้จะถูกนำไปใช้ในการทดสอบระบบรวมในหัวข้อถัดไป และอาจมีการปรับแต่งเพิ่มเติมตามสภาพการใช้งานจริง

## 4.2 การทดสอบฮาร์ดแวร์ (Hardware Testing)

วัตถุประสงค์ของการทดลอง

เพื่อวัด “ความหน่วงเวลาของระบบ (End-to-End Hardware Latency)” นับตั้งแต่ส่งคำสั่งเคลื่อนที่จากโปรแกรม Python → ผ่าน PySerial → ไปยัง ESP32 → ขับมอเตอร์ → จนกระทั่งตำแหน่งของเมาส์ (หรือเคอร์เซอร์) เริ่มเคลื่อนที่จริงบนหน้าจอ

ค่าที่ได้จะถูกนำไปใช้:

- วิเคราะห์ข้อจำกัดด้านการตอบสนองของระบบ
- อธิบายสาเหตุของความยากในการปรับ PID ให้ตอบสนองเร็ว
- อ้างอิงประกอบในการอธิบายผลการทดสอบ Scenario ที่ต้องการความเร็วสูง เช่น Tracking เป้าหมายเร็ว

ตัวแปรที่ใช้ในการทดลอง

- ตัวแปรต้น (Independent Variable): ทิศทางการเคลื่อนที่ (ขึ้น/ลง)
- ตัวแปรตาม (Dependent Variable): ค่าความหน่วง (Latency, หน่วย: ms)
- ตัวแปรควบคุม (Controlled Variables):
  - ความเร็วที่สั่งไปยังล้อ (SPEED = 70%)
  - ตำแหน่งเริ่มต้นของเมาส์ (Y0) บนหน้าจอ
  - ขนาดของการเปลี่ยนแปลงตำแหน่งที่ต้องตรวจจับ (THRESHOLD = 5 px)
  - พอร์ตอนุกรมและอัตรา Baud (COM5@115200)

ขั้นตอนการทดลอง

1. ตำแหน่งของเคอร์เซอร์จะถูกจับที่ตำแหน่งปัจจุบัน (y0)
2. ส่งคำสั่งขับล้อทุกล้อในทิศทางที่กำหนดเป็นช่วงสั้น (impulse) ด้วยค่า PWM ที่เท่ากัน (เช่น +70%)
3. บันทึกเวลาส่งคำสั่ง (t₀)
4. หยุดล้อทันทีด้วยคำสั่ง 0,0,0,0
5. รอจนกว่าเคอร์เซอร์จะขยับจากตำแหน่งเดิมอย่างน้อย 5px (ขึ้นหรือลง)
6. บันทึกเวลาปัจจุบัน (t₁) แล้วคำนวณ latency = t₁ – t₀
7. ทำซ้ำทั้งหมด 10 ครั้งต่อทิศทาง (ขึ้น/ลง)

โค้ดสำคัญที่ใช้

ในไฟล์ test_latency.py ใช้ฟังก์ชัน run_tests(direction, sender) เพื่อวัดค่าความหน่วง:

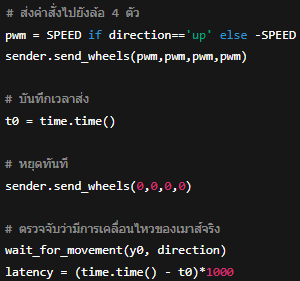
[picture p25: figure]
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

ผลการทดลอง

- ค่าเฉลี่ย Latency (ms):
  - ขึ้น (Up): 48.6 ms
  - ลง (Down): 49.7 ms
- ช่วง Latency: 45.3 ms – 63.6 ms

วิเคราะห์ผล

- ค่าความหน่วงเฉลี่ยของระบบอยู่ที่ประมาณ 48–50 ms ซึ่งถือว่า “ค่อนข้างมาก” หากเทียบกับเป้าหมายที่ต้องการระบบตอบสนองในระดับ ≤16 ms (เพื่อเล็งแบบ FPS-ระดับแข่งขัน)
- ตัวแปรสำคัญที่ส่งผลต่อความหน่วง:
  - PySerial I/O Delay (~1–2 ms)
  - Delay จาก Software Stack (Interpreter, Threading)
  - Wireless Latency จากเมาส์ Logitech G Pro X Superlight (แม้จะใช้ 1000 Hz polling แต่ยังมี latency ประมาณ 1–5 ms โดยธรรมชาติของ wireless)
  - มอเตอร์มีอินเอร์เชีย (Inertia) ทำให้ล้อเริ่มหมุนช้า
- ค่า Spike บางครั้งทะลุ 60 ms อาจมาจาก Load พื้นหลังใน Windows หรือ USB stack

ความเกี่ยวข้องกับการจูน PID

- ความหน่วงสูงนี้ส่งผลให้ระบบ ตอบสนองช้าเกินไปเมื่อเป้าหมายเคลื่อนที่เร็ว
- หากไม่คำนึงถึง latency นี้ในการตั้งค่า Kd หรือ Kp อาจทำให้ระบบ overreact → overshoot → เล็งไม่ทันเป้า
- การทดสอบ latency นี้จึงช่วยให้เข้าใจ “ความหน่วงสะสมของระบบ” ก่อนเริ่มปรับจูนจริง และอธิบายสาเหตุที่การจูน PID ให้ตอบสนองเร็วในเป้าหมาย dynamic นั้น ยากกว่าที่คาด

## 4.3 การทดสอบระบบรวมในสภาพแวดล้อมจริง (Full-System Integration Test in Real Scenarios)

### 4.3.1 การทดสอบเปรียบเทียบผลลัพธ์ของโมเดลในสถานการณ์จริง (Model Integration Testing with Real Scenarios)

วัตถุประสงค์ของการทดลอง

เพื่อประเมินความสามารถของโมเดล YOLOv5 ขนาดต่าง ๆ (small_old, small_new, medium, large, xlarge) ในการตรวจจับเป้าหมายจากหน้าจอเกม Kovaak และควบคุมหุ่นยนต์เพื่อติดตามและคลิกเป้าหมายแบบเรียลไทม์ โดยพิจารณาคะแนน (Score) และความแม่นยำ (Accuracy) ที่ระบบทำได้ในสถานการณ์ที่หลากหลายจริงในเกม ซึ่งช่วยยืนยันผลจากการทดลองซอฟต์แวร์ก่อนหน้า (4.1.1 – 4.1.3) ว่าโมเดลใดเหมาะสมกับระบบ Aimbot จริง

ตัวแปรในการทดลอง

- ตัวแปรต้น (Independent Variable):
  - ขนาดของโมเดล YOLOv5 ที่ใช้งาน ได้แก่ small_old, small_new, medium, large, xlarge
- ตัวแปรควบคุม (Controlled Variables):
  - สเปกเครื่องทดสอบ: ASUS TUF A15, CPU Ryzen 7 5800H, RAM 16GB, GPU RTX 3060 Laptop Max-Q
  - ความละเอียดหน้าจอ: 1920×1080, V-sync OFF
  - Software version: PyTorch 2.1, YOLOv5 PyTorch
  - PID controller ที่ใช้: ค่าที่ได้จากการจูนในหัวข้อ 3.6.5 (ค่าคงที่ทุกการทดลอง)
  - สถานที่และสภาพแวดล้อมของเกม: เหมือนกันทุกการทดสอบ
  - ระยะเวลาในการเล่นแต่ละ Scenario: ตามเวลาของ Scenario จริง (ประมาณ 60 วินาที)
  - การคลิก: ใช้โหมดคลิกในระบบ (mode 2: pulse-click) ที่เปิดใช้งานเมื่อเป้าเข้าสู่กล่องกลางจอ (On Target)
- ตัวแปรตาม (Dependent Variable):
  - ค่าคะแนนรวม (Score)
  - ค่าความแม่นยำ (Accuracy %)
  - ระดับความแม่นยำของโมเดลเมื่อประยุกต์ใช้ในสถานการณ์จริง

ขั้นตอนการทดลอง

1. เตรียมระบบให้พร้อมใช้งานในโหมด Integration ที่สมบูรณ์ (ตามที่พัฒนาเสร็จในหัวข้อ 3.6.6)
2. โหลดโมเดล YOLOv5 ขนาดที่ต้องการทดสอบ
3. เปิดโปรแกรม Kovaak และเลือก Scenario ที่กำหนด
4. เริ่มรันทดสอบ โดยให้ระบบควบคุมหุ่นยนต์และยิงเป้าหมายแบบอัตโนมัติผ่านการตรวจจับจากกล้อง
5. เมื่อจบการเล่นแต่ละรอบ ให้บันทึกค่าคะแนนและ Accuracy ที่ได้จาก Kovaak
6. ทำซ้ำขั้นตอนข้างต้นกับโมเดลทุกตัว และกับ Scenario ทั้งหมด

รายการ Scenario ที่ใช้ในการทดลอง

เลือกจาก Kovaak ที่มีความหลากหลายของเป้าหมายเพื่อทดสอบระบบในหลายเงื่อนไข:

ชื่อ Scenario | รายละเอียด | วัตถุประสงค์ของการเลือก
Close Long Strafes Robot Warzone | Bot วิ่งใกล้ มีหัว กระโดด ย่อ หลบ | ทดสอบระบบในสภาวะ “หนักมาก” ที่เป้าหมายมีการเคลื่อนไหวสูงและ dynamic สูง
Kindaclose Long Strafes Robot | Bot ลำตัวยาว ระยะไกลขึ้น ไม่มีการย่อ | ทดสอบระบบในเงื่อนไขของระยะไกลและโครงสร้างเป้าหมายเปลี่ยน
Close Fast Strafes Easy Invincible Robot 25% Slower | Bot ตัวหนา เคลื่อนที่เร็วปานกลาง | ทดสอบระบบในเงื่อนไขกลาง ๆ ที่ควบคุมได้ง่ายขึ้น

หมายเหตุเกี่ยวกับการวัดผล

- ค่าคะแนนจะเปรียบเทียบกับ “ค่าเฉลี่ยของผู้เล่นทั่วไป” ที่มีในฐานข้อมูลของ Kovaak
- ผู้วิจัยจะทำการประเมินว่าโมเดลแต่ละตัวมีความสามารถอยู่ในระดับใด เช่น อยู่ใน Percentile ใดของผู้เล่นทั่วไป
- เนื่องจากข้อจำกัดด้านเวลาและทรัพยากรการทดสอบ จะดำเนินการ เพียงหนึ่งรอบต่อโมเดลในแต่ละ Scenario เท่านั้น โดยยึดตามหลักวิศวกรรมที่ว่าสภาพแวดล้อมควบคุมได้เหมือนกันทุกครั้ง

หมายเหตุเพิ่มเติม

- การทดลองนี้เน้นการประเมินภาพรวมของระบบในการทำงานกับเกมจริงแบบ end-to-end ไม่เน้นการวิเคราะห์พฤติกรรมของ PID controller โดยตรง จึง ไม่มีการเก็บ log หรือ plot กราฟ dx/dy เพิ่มเติม

การปรับวิธีการทดสอบจากแผนเดิม

จากแผนการทดสอบเดิม ผู้วิจัยได้ปรับวิธีการทดสอบบางประการเพื่อให้เหมาะสมกับข้อจำกัดของระบบและความเป็นจริงของการทดลอง ได้แก่:

- ไม่สามารถใช้ Percentile เทียบกับฐานข้อมูลของ Kovaak ได้ เนื่องจากระบบ Kovaak นับคะแนนสูงสุดของผู้ใช้เป็น baseline ส่งผลให้ไม่สามารถใช้ percentile เปรียบเทียบระหว่างโมเดลได้อย่างยุติธรรม
- หากเป้าหมายหลุดออกนอกหน้าจอ ผู้วิจัยจะทำการ “หมุนกล้องด้วยตนเอง” เพื่อให้กลับเข้าสู่เฟรม แล้วปล่อยให้ระบบทำงานต่อโดยอัตโนมัติ เพื่อเลี่ยงกรณีที่ระบบไม่สามารถทำงานต่อได้ (ยังไม่ได้พัฒนา logic ติดตามเป้าแบบ full 360°)
- วิธีการนับ Accuracy และ Score ยึดตามการตรวจจับที่ “ยิงถูกเป้า” เท่านั้น กล่าวคือระบบจะคลิกเมื่อเป้าอยู่ในกล่องเล็ง และจะนับว่าถูกก็ต่อเมื่อเกิดการโดนเป้าในเกมจริง

ทั้งนี้ การทดสอบดังกล่าวมีผลกระทบต่อ "ค่าเฉลี่ยคะแนนจริงของผู้วิจัยในระบบ Kovaak" อย่างชัดเจน

(กล่าวอย่างวิศวกรผู้เสียสละ: “ระบบดีขึ้น แต่สถิติส่วนตัวพังยับ”)

สรุปผลการทดสอบ

Model | Scenario | Score | Accuracy | ความเห็นทางเทคนิค
Small Old | Warzone | 10 | 22.7% | แทบไม่ตรวจเจอ โดยเฉพาะเมื่อเป้าย่อ – คาดว่า dataset มี bias อย่างมาก
| Kindaclose Long | 36 | 100% | ตรวจเจอ 2 เป้าทั้งหมด 2 อัน แต่จำนวนเป้าที่ detect ได้มีน้อยมาก
| Easy 25% | 108 | 50.0% | ตรวจไม่เจอเลยเกือบทั้งฉาก – บางเฟรมไม่คลิกเลยเพราะไม่เจอเป้า
Small New | Warzone | 313.97 | 23.6% | ตรวจเจอเฉพาะเป้าที่ไม่ย่อ – motion control ดีเมื่อเจอเป้า
| Kindaclose Long | 540 | 29.7% | ตรวจเจอแต่ไม่บ่อย – motion control ดีกว่า small_old
| Easy 25% | 828 | 36.8% | ตรวจเป้าตรงกลางได้ดี แต่หลุดบ่อยเวลาเป้าหันข้าง
Medium | Warzone | 198.09 | 14.9% | ตรวจเจอแทบตลอด – ระบบ over-shoot บ่อยเมื่อเป้าหมายอยู่ไกล
| Kindaclose Long | 306 | 11.3% | ตรวจเจอได้ต่อเนื่อง – แต่ motion overshoot ทำให้ accuracy ลดลง
| Easy 25% | 324 | 9.5% | ตรวจเป้าได้ประมาณ 70% ของเวลา แต่ระบบวิ่งตามเป้าไม่ทันในบางจังหวะ
Large | Warzone | 121.65 | 10.9% | ตรวจเจอทุก frame แต่ motion overshoot ทำให้ยิงไม่เข้าเป้า
| Kindaclose Long | 666 | 19.9% | ตรวจเจอดีมาก – PID ต้องละเอียดกว่านี้เพื่อให้เข้าเป้าแม่นขึ้น
| Easy 25% | 504 | 11.8% | ตรวจได้ตลอด – แต่เป้าหมายเคลื่อนที่เร็ว ทำให้ไม่สามารถเกาะได้ตลอด
X-Large | Warzone | 30.09 | 6.4% | ตรวจได้ แต่ Aimbot View กระตุกอย่างหนัก (~20–30 FPS)
| Kindaclose Long | 270 | 14.2% | ตรวจเป้าได้ตลอด – ระบบวิ่งออกนอกเป้าหมายบ่อย
| Easy 25% | 198 | 7.3% | คล้าย large แต่ด้วย latency ทำให้ระบบตอบสนองไม่ทัน

หมายเหตุ: ค่าคะแนนเปรียบเทียบกับ median ของผู้เล่นทั่วไป:

- Warzone: ~8,587.63
- Kindaclose Long: ~15,192
- Easy 25%: ~11,952

วิเคราะห์ผลการทดสอบ

1) ความสามารถในการตรวจจับเป้า (Detection Capability)

- Small_old: ตรวจจับไม่ได้ในสถานการณ์ที่มี dynamic สูงหรือเป้าย่อ – แสดงให้เห็นว่ารูปแบบ dataset ยังไม่ครอบคลุมเพียงพอ
- Small_new: ตรวจจับได้ดีกว่าเดิมโดยเฉพาะกับเป้าที่หันหน้า – แต่ยังหลุดในบาง frame โดยเฉพาะเป้าหมายที่หันข้าง
- Medium ขึ้นไป: เริ่มมี performance ที่เสถียรในการตรวจจับ – ตรวจได้เกือบตลอด frame แต่ความแม่นยำยังต่ำเพราะ motion overshoot
- X-Large: ตรวจได้เสถียรแต่ไม่สามารถทำงานได้จริง เนื่องจาก latency สูง และ FPS ลดลงจนระบบควบคุมตอบสนองไม่ทัน

2) ความสามารถในการเคลื่อนตามเป้า (Motion Control)

- Overshoot เกิดในโมเดลขนาดกลางถึงใหญ่ โดยเฉพาะใน Scenario ที่เป้าหมายเคลื่อนที่เร็ว
- สาเหตุอาจมาจาก:
  - ระบบ PID ที่จูนในความเร็วต่ำ แต่นำไปใช้งานใน Scenario ที่เร็วเกินไป
  - ตัวแอป Kovaak เป็นแอปสำหรับการฝึกจริงจัง ทำให้ไม่มี Scenario ที่เป้าเคลื่อนช้าให้ใช้ในการเทรนหรือทดสอบ

3) ปัจจัยที่ส่งผลต่อผลลัพธ์

- คุณภาพของ Dataset และมุมมองที่ใช้ในการ train ส่งผลอย่างมากกับความสามารถในการตรวจจับ
- Latency และ FPS ของ Aimbot View เมื่อใช้โมเดลขนาดใหญ่ ส่งผลต่อความสามารถของระบบ PID อย่างชัดเจน
- ระบบคลิกแบบ On-Target ช่วยลด false positive แต่ทำให้คะแนนต่ำถ้า motion เข้าเป้าไม่ทัน
- การหมุนกล้องเองเมื่อตรวจไม่เจอเป้า เป็นการแก้ปัญหาเฉพาะหน้าและจะมีการพัฒนาให้ระบบทำได้อัตโนมัติในอนาคต

สรุปเชิงวิศวกรรม

- การทดสอบนี้แสดงให้เห็นว่า แม้ระบบตรวจจับจะมีศักยภาพสูง (ใน medium ขึ้นไป) แต่หากระบบควบคุม (PID) และการตอบสนองของระบบรวมไม่เหมาะสม ก็ไม่สามารถสร้าง output ที่แม่นยำได้
- การเลือกโมเดล YOLOv5 ขนาดใหญ่ไม่ได้แปลว่าจะได้ผลลัพธ์ที่ดีที่สุดเสมอไป หากระบบควบคุมหรือฮาร์ดแวร์ไม่สามารถรองรับได้
- โมเดลระดับ medium เป็นจุดสมดุลที่ดีที่สุดในระบบปัจจุบัน เมื่อพิจารณาจาก FPS, Accuracy และความสามารถในการ tracking

### 4.3.2 การทดสอบ PID บนสถานการณ์จริง (PID Validation in Real Scenarios)

วัตถุประสงค์ของการทดลอง

เพื่อประเมินประสิทธิภาพของ PID Controller ที่ได้รับการปรับจูนในหัวข้อ 3.6.5 เมื่อใช้งานร่วมกับโมเดล Object Detection และระบบควบคุมหุ่นยนต์จริง โดยเน้นการวิเคราะห์เชิงพฤติกรรมจากกราฟ error (dx, dy) ที่ได้จากการ Log การทำงานจริง ไม่ได้ใช้สถิติจากคะแนนของเกมเป็นหลัก

ตัวแปรในการทดลอง

- ตัวแปรต้น (Independent Variables):
  - ลักษณะของ Scenario ในเกม Kovaak (เช่น ความเร็ว, การกระโดด, การ teleport)
  - พฤติกรรมการเคลื่อนไหวของเป้าหมาย
- ตัวแปรควบคุม (Controlled Variables):
  - โมเดล Object Detection: YOLOv5s (เวอร์ชันใหม่)
  - สภาพแวดล้อมของเครื่องทดสอบ: ASUS TUF A15, RTX 3060 Laptop Max-Q
  - ความละเอียดหน้าจอ: 1920×1080
  - ความไวเมาส์: 50 cm/360°
  - ค่าคงที่ของ PID: ใช้ค่าที่ปรับจูนแล้วจากหัวข้อ 3.6.5
  - โค้ดที่ใช้รันระบบ: main.py, wheel_control.py, pid.py, serial_sender.py, logger.py
- ตัวแปรตาม (Dependent Variables):
  - กราฟ dx, dy (Pixel error) ต่อเวลา
  - การเปลี่ยนแปลงของ error และการแกว่ง (oscillation) ของระบบ
  - ความสามารถในการเข้าเป้า (On-Target Stability)

รูปแบบการทดลอง

ในการทดลองนี้จะใช้เพียงโมเดลเดียวคือ YOLOv5s (new) ซึ่งเป็นโมเดลขนาดเล็กที่มีความสมดุลระหว่างความแม่นยำและความเร็ว เหมาะกับระบบควบคุมแบบเรียลไทม์ โดยจะทำการทดสอบใน 2 Scenarios จาก Kovaak ที่เลือกอย่างระมัดระวังเพื่อจำลองสภาพแวดล้อมที่แตกต่างกัน และประเมินพฤติกรรมของระบบ PID ที่ปรับจูนไว้ในสถานการณ์จริงที่หลุดจาก sandbox:

Scenario ที่ใช้ในการทดสอบ

1. Blaze33 – Kindaclose Mid Strafes Robot Blink
  - เป้าหมายเดินระดับปานกลาง มีการ teleport (Blink) เป็นครั้งคราว
  - ความเร็วไม่สูงมาก แต่มีลักษณะ jump & blink สร้างความท้าทายกับ PID
  - เหมาะสำหรับดูพฤติกรรมระบบที่ไม่ใช่ high-speed tracking
2. Close Short Strafes Easy Invincible Robot
  - เป้าหมายวิ่งเร็วต่อเนื่องแบบไม่มี pause และไม่มี hitbox
  - มีลักษณะเป็น target รูปร่างมนที่เคลื่อนไหวเร็ว (แต่มนุษย์เล่นยังถือว่า “easy”)
  - เหมาะสำหรับประเมินความสามารถของ PID ในการลด overshoot ขณะเคลื่อนไหวเร็ว

วิธีการทดลอง

1. เริ่มต้นรันระบบด้วยโค้ด main.py ที่รวมการทำงานของ Object Detection, PID และการส่งคำสั่งไปยัง ESP32
2. ใช้ logger.py บันทึกข้อมูล (dx, dy, mode) ทุกเฟรมขณะรัน Scenario จริง (โหมด 1 → PID Control เปิด)
3. จบการทดลองเมื่อ Scenario จบ → บันทึก Log เป็น .csv
4. ใช้ plotter.py วาดกราฟ dx, dy เพื่อตรวจสอบลักษณะของ error และความเสถียรของการควบคุม
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

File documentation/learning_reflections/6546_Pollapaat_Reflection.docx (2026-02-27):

Reflection

Name: Pollapaat Suttimala

Advisor: SURIYA NATSUPAKPONG

Topic: Physical Aimbot for FPS Games using Computer Vision

What have you done right in the previous phase?

1. I thoroughly researched and evaluated the physical mechanism required for the project, including compiling a detailed list of components and selecting communication methods (using PySerial) and board options (ESP32).
2. I proactively reached out to an expert who has executed a similar project, gaining valuable insights on hardware selection and design strategies, which helped shape the project's direction.
3. I initiated the CAD design process and began organizing the mechanical layout, ensuring that our component choices align with the project’s objectives and future integration with the computer vision module.

…

What could you have done better?

1. I could have adhered more strictly to the planned timeline; my progress was slower than expected due to unforeseen health issues.
2. Better documentation of early design iterations and prototype tests would have provided clearer benchmarks for improvement.
3. I need to refine my focus and time management to balance the mechanical development and preparation for the machine learning aspects more effectively.

…

What do you aim to achieve next?

1. Finalize the CAD design and monitor the delivery of the hardware components that have already been ordered online.
2. Assemble the physical parts as soon as they arrive, and rigorously test the assembly to ensure smooth movement and calibration.
3. Begin the integration and testing of the computer vision module, with a focus on addressing latency issues between image capture and motor response.

…

What are changes in the plan?

1. The project timeline has been adjusted to account for a 1-2 week delay due to slower progress and personal health setbacks.
2. Although the overall project scope remains the same, the schedule now reflects a slight delay while still emphasizing the key areas of mechanical design and computer vision integration.
3. The motor choice has been updated from a stepper motor to a micro DC motor to better suit the project's .

…

How do you feel toward this work right now?

I feel excited and challenged by the work ahead. Despite some setbacks and delays, I remain highly motivated to overcome obstacles and make significant progress. The complexity and integration of robotics with computer vision continue to inspire me to push forward.

How has your advisor treats you (academics, research skills, personal support, …)?

So far, I have simply updated my progress during this phase, and my advisor has been professional and supportive. Although his involvement has been limited in this mechanical phase, I anticipate that his role will become significantly more active during the next phase—especially when I begin developing and refining the computer vision model.

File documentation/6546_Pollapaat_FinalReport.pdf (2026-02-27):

Physical Aimbot ส ำหรับเกม FPS ด้วย Computer Vision

นำยภนลภัส สุทธิมำลำ รหัศนักศึกษำ 65340500046

โครงงำนนี้เป็นส่วนหนึ่งของกำรศึกษำตำมหลักสูตร ปริญญำวิศวกรรมศำสตรบัณฑิต สำขำวิชำวิศวกรรมหุ่นยนต์และระบบอัตโนมัติ สถำบันวิทยำกำรหุ่นยนต์ภำคสนำม มหำวิทยำลัยเทคโนโลยีพระจอมเกล้ำธนบุรี ปีกำรศึกษำ 2567

Source Code Repository : https://github.com/mudmini009/FRA361_Open_Topic.git

สารบัญ

บทที่ 1 บทน ำ | 6
1.1 ที่มา ความส าคัญ | 6
1.2 ประโยคปัญหางานวิจัย (Problem Statement) | 6
1.3 ผลผลิตและผลลัพธ์(Outputs and Outcomes) | 7
ผลผลิต | 7
ผลลัพธ์ | 7
1.4 ความต้องการของระบบ (Requirements) | 7
1.5 ขอบเขตของงานวิจัย (Scopes) | 7
1.6 ข้อก าหนดของงานวิจัย (Assumptions) | 8
1.7 ขั้นตอนการด าเนินงาน | 8
บทที่ 2 ทฤษฎี/งำนวิจัย/กำรศึกษำที่เกี่ยวข้อง | 10
2.1Computer Vision ส าหรับ Object Detection | 10
2.1.1 หลักกำรท ำงำนพื้นฐำนของ YOLO (You Only Look Once) | 10
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

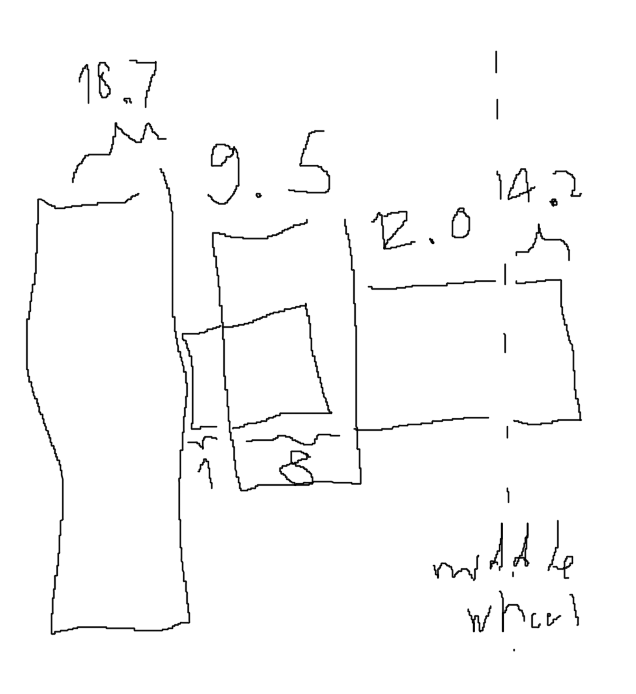
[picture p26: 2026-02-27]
CAD/Browse Dimension/motorwith wheel.png

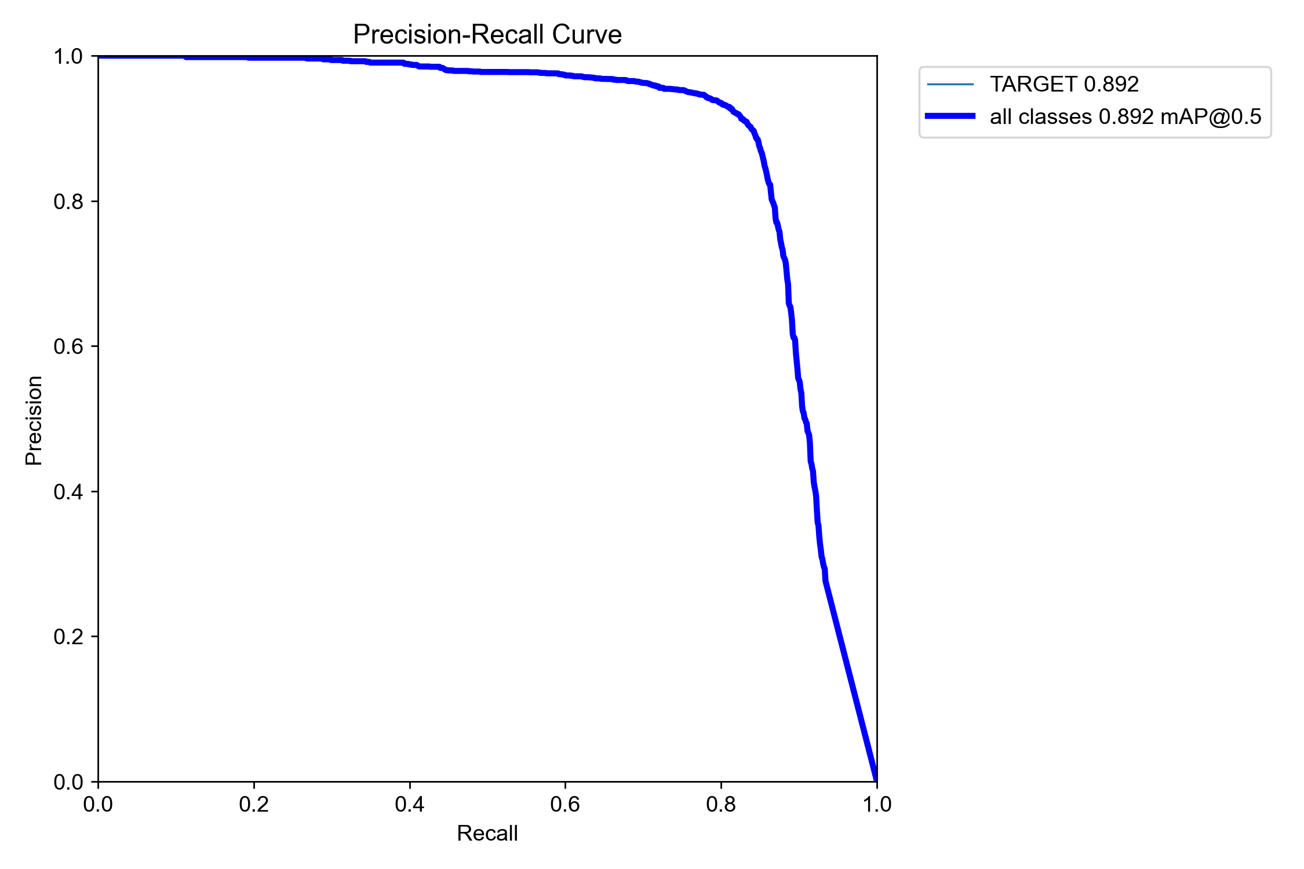
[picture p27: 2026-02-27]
models/model1(y5s)/PR_curve.png

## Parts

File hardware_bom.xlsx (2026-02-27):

รายการ | ชื่อสินค้า | น๊อตที่ใช้ | ราคาต่อชิ้น | จำนวน | ราคารวม | ค่าจัดส่ง | รวมค่าส่ง | ลิงก์สินค้า | ขอใบกำกับภาษีได้ | เบิกเงินแล้ว | สั่งแล้ว | ไปเอาของแล้ว | หมายเหตุ
1 | Wention USB A - C 3m |  | 48 | 1 | 48 | 0 | 48 | https://th.shp.ee/FMJBAgB | FALSE | FALSE | TRUE | FALSE | Flash sale
2 | PETG Pink |  | 399 | 1 | 399 | 0 | 399 | https://th.shp.ee/HT2Zsog | TRUE | FALSE | TRUE | TRUE | เผื่อ 1
3 | DRV8833 Driver |  | 24 | 3 | 72 |  | 72 | https://th.shp.ee/RQFnjmf | TRUE | FALSE | TRUE | TRUE
4 | ก้างปลาตัวผู้ |  | 5 | 2 | 10 |  | 10 | https://th.shp.ee/MKHim3K | TRUE | FALSE | TRUE | TRUE
5 | รางถ่าน 18650 2 แถว |  | 10 | 1 | 10 |  | 10 | https://th.shp.ee/3De5q4a | TRUE | FALSE | TRUE | TRUE
6 | ESP32 38 pin Type C |  | 149 | 1 | 149 |  | 149 | https://th.shp.ee/AxCGxyB | TRUE | FALSE | TRUE | TRUE
7 | สาย 20 cm ผู้-ผู้ ผู้-เมีย เมีย-เมีย |  | 24 | 3 | 72 |  | 72 | https://th.shp.ee/N3h4Mzb | TRUE | FALSE | TRUE | TRUE
8 | ถ่าน 18650 โง่ๆ |  | 20 | 4 | 80 |  | 80 | https://th.shp.ee/C3Y6MnY | TRUE | FALSE | TRUE | TRUE | สามารถสลับใช้ได้ระหว่างรอชาร์จ
9 | เกียร์ motor 1:48 (6-8 voltage) |  | 18 | 4 | 72 |  | 72 | https://th.shp.ee/fErTuac | TRUE | FALSE | TRUE | TRUE
10 | XL4016E1 Stepdown |  | 75 | 1 | 75 |  | 75 | https://th.shp.ee/P6KnB88 | TRUE | FALSE | TRUE | TRUE
11 | Mecanum 48mm 4 ล้อ |  | 252 | 1 | 252 |  | 252 | https://th.shp.ee/BsWaJgv | TRUE | FALSE | TRUE | TRUE
12 |  |  |  |  | 0 |  | 0 |  | FALSE | FALSE | FALSE | FALSE
13 |  |  |  |  | 0 |  | 0 |  | FALSE | FALSE | FALSE | FALSE
14 |  |  |  |  | 0 |  | 0 |  | FALSE | FALSE | FALSE | FALSE
15 |  |  |  |  | 0 |  | 0 |  | FALSE | FALSE | FALSE | FALSE
16 |  |  |  |  | 0 |  | 0 |  | FALSE | FALSE | FALSE | FALSE
17 |  |  |  |  | 0 |  | 0 |  | FALSE | FALSE | FALSE | FALSE
18 |  |  |  |  | 0 |  | 0 |  | FALSE | FALSE | FALSE | FALSE
19 |  |  |  |  | 0 |  | 0 |  | FALSE | FALSE | FALSE | FALSE
20 |  |  |  |  | 0 |  | 0 |  | FALSE | FALSE | FALSE | FALSE
21 |  |  |  |  | 0 |  | 0 |  | FALSE | FALSE | FALSE | FALSE
22 |  |  |  |  | 0 |  | 0 |  | FALSE | FALSE | FALSE | FALSE
23 |  |  |  |  | 0 |  | 0 |  | FALSE | FALSE | FALSE | FALSE
24 |  |  |  |  | 0 |  | 0 |  | FALSE | FALSE | FALSE | FALSE
25 |  |  |  |  | 0 |  | 0 |  | FALSE | FALSE | FALSE | FALSE
26 |  |  |  |  | 0 |  | 0 |  | FALSE | FALSE | FALSE | FALSE
27 |  |  |  |  | 0 |  | 0 |  | FALSE | FALSE | FALSE | FALSE
รวม

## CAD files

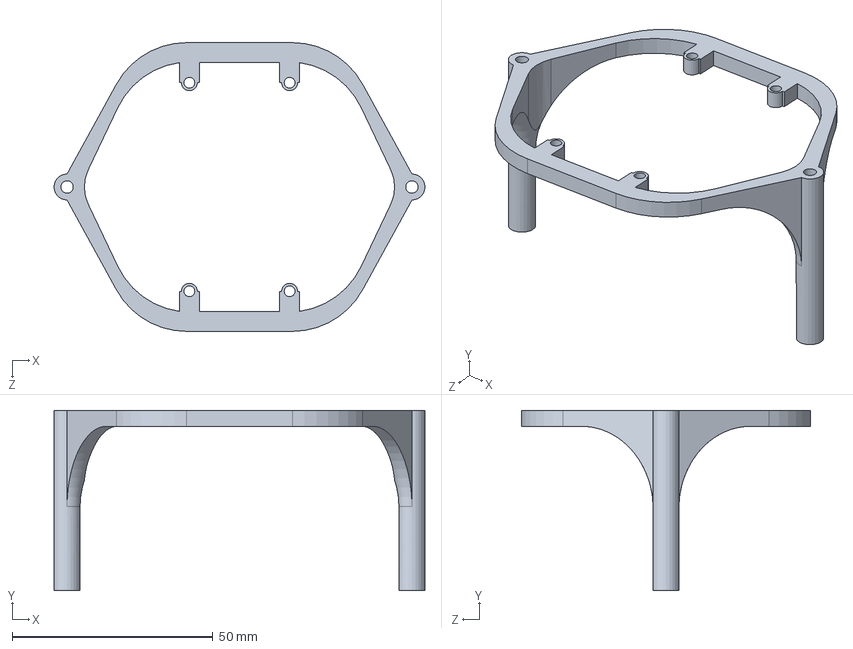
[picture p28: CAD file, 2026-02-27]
CAD/draw part/Esp32Base.SLDPRT
92.5 x 45.0 x 72.0 mm

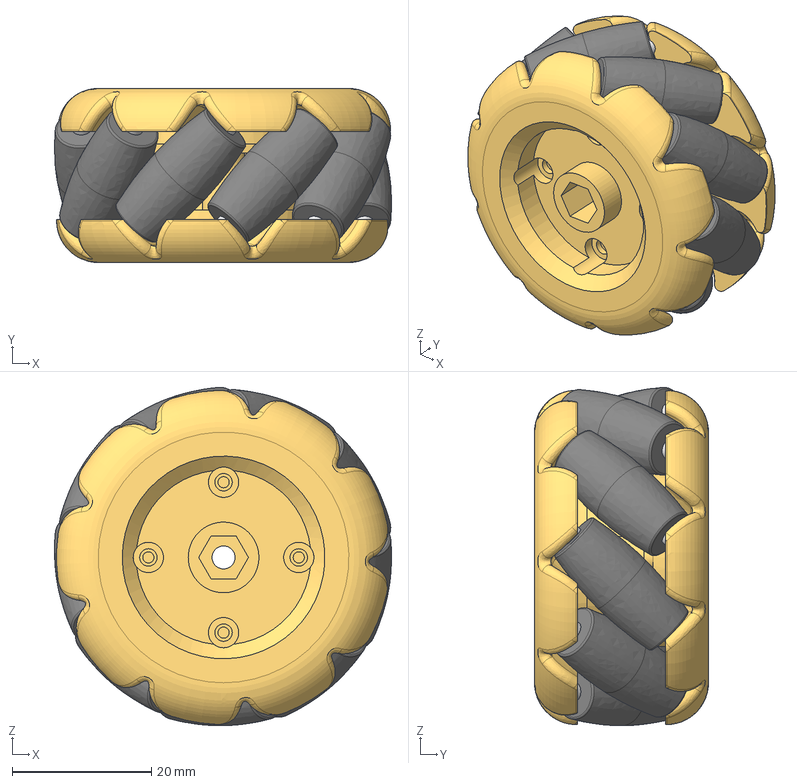
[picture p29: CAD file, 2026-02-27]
CAD/exist part/Mecanum Left v5.step
48.4 x 25.0 x 48.6 mm
Side1
Side 2
Roller x 9

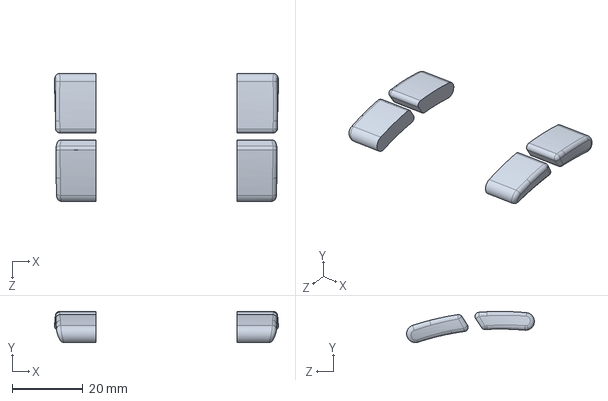
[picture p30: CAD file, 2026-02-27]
CAD/exist part/Mouse_Pro Wireless Gaming Mouse/Buttons.SLDPRT
63.5 x 8.83 x 36.2 mm

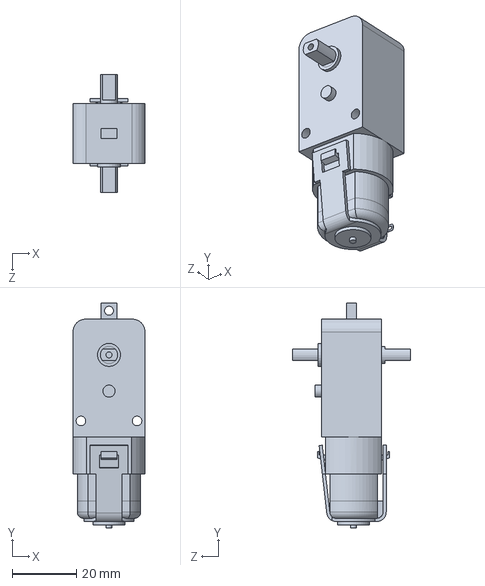
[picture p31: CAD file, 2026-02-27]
CAD/TT Motor.step.SLDPRT
22.5 x 70.2 x 36.8 mm

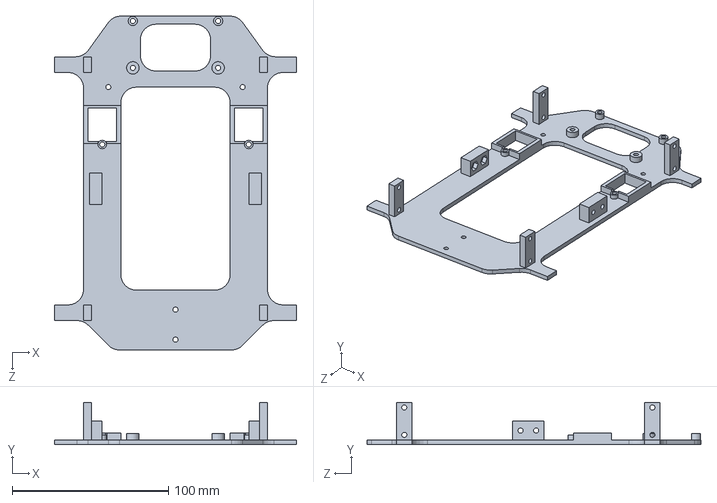
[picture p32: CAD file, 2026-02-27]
CAD/draw part/Basedown.SLDPRT
155.0 x 27.0 x 213.8 mm

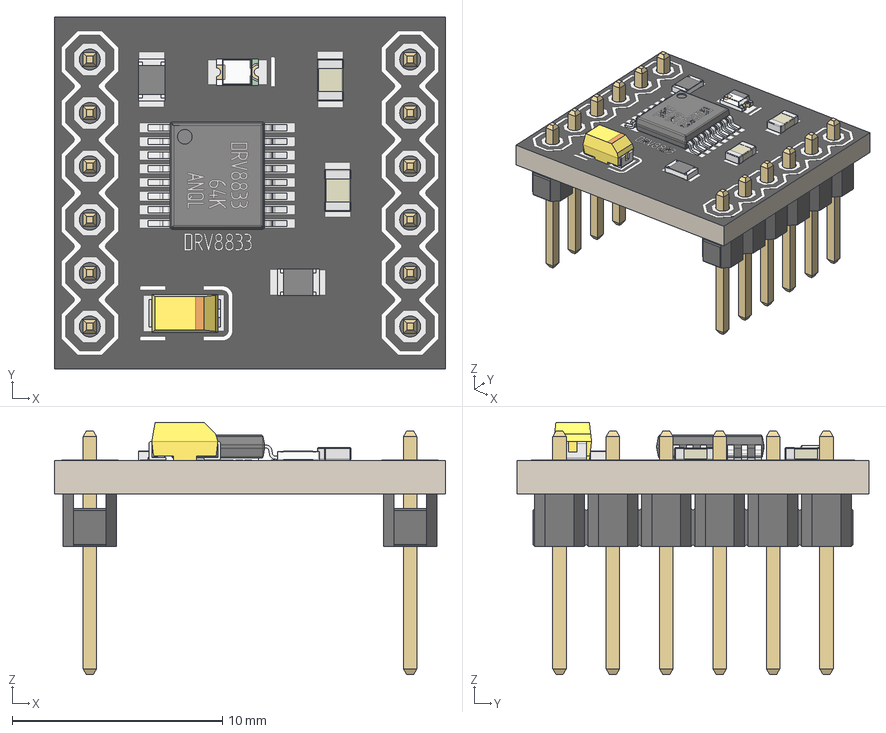
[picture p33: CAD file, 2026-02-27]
CAD/exist part/Modulo_DRV8833_A.stp
18.6 x 16.8 x 12.0 mm
placa
TSSOP_cuerpo_1.2h
TSSOP_pin_6.6 x 2
PIN_macho_1x6 x 2
T494A
C0805_060 x 2
R0805 x 2
housing
marking x 2
cover
base_2
base

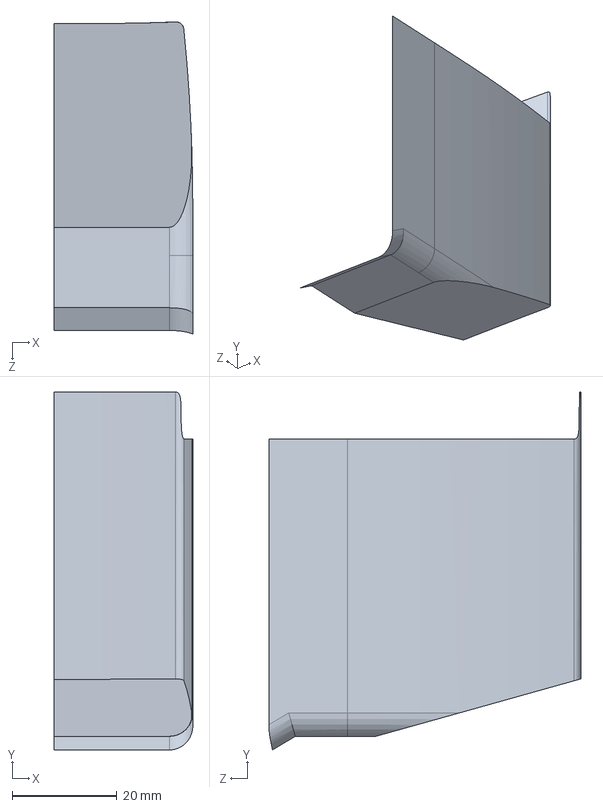
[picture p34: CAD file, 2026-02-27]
CAD/exist part/Mouse_Pro Wireless Gaming Mouse/Mouse_Hero_MASTER.SLDPRT
26.6 x 68.4 x 59.7 mm

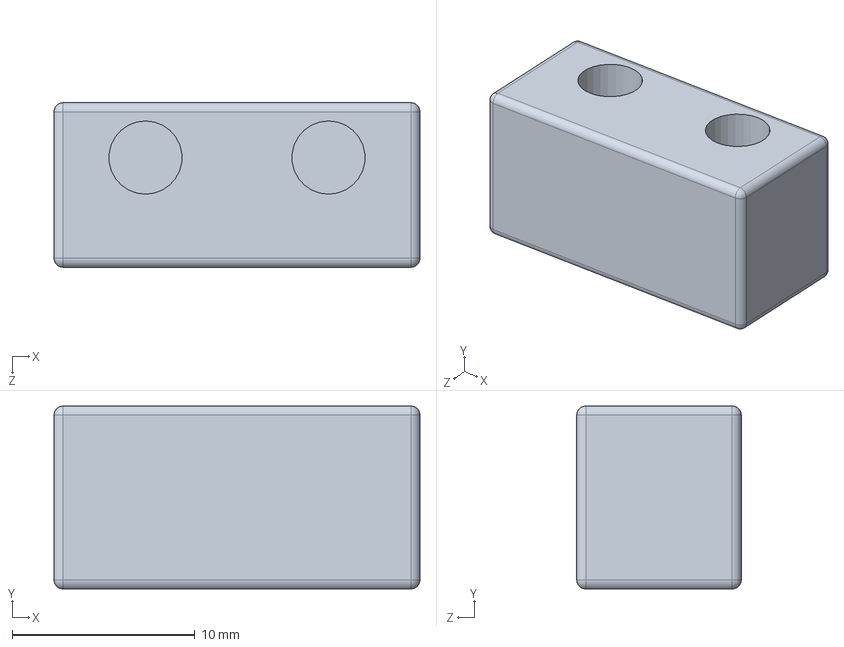
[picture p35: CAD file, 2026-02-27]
CAD/draw part/MouseLockV2.SLDPRT
20.0 x 10.0 x 9.00 mm

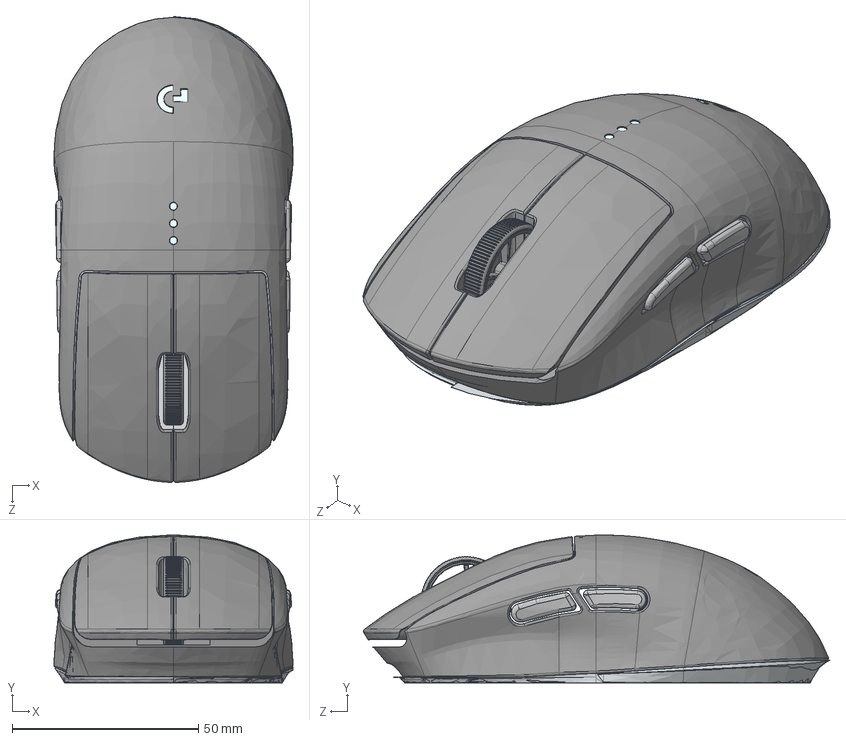
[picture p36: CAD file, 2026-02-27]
CAD/exist part/Mouse_Pro Wireless Gaming Mouse/Mouse_Hero.STEP
64.2 x 39.7 x 125.2 mm
Base
wheel
Buttons

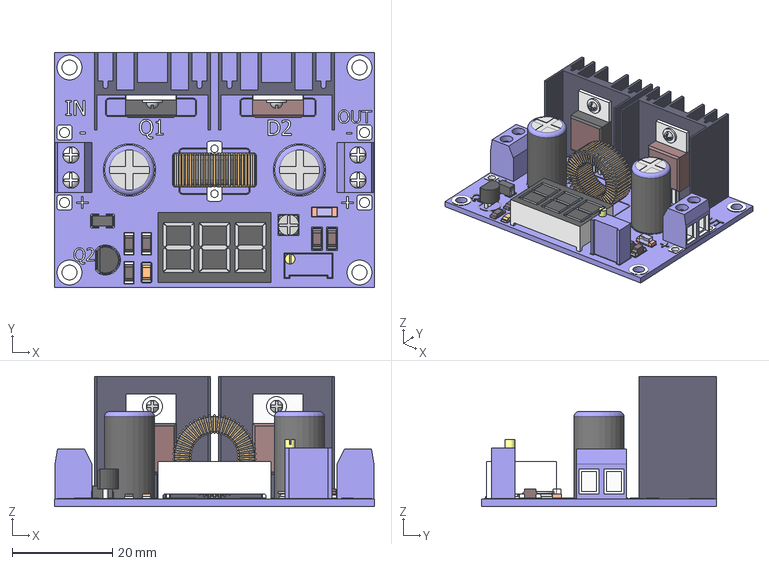
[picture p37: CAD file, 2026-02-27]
CAD/exist part/XL4016.stp
64.0 x 47.0 x 26.0 mm

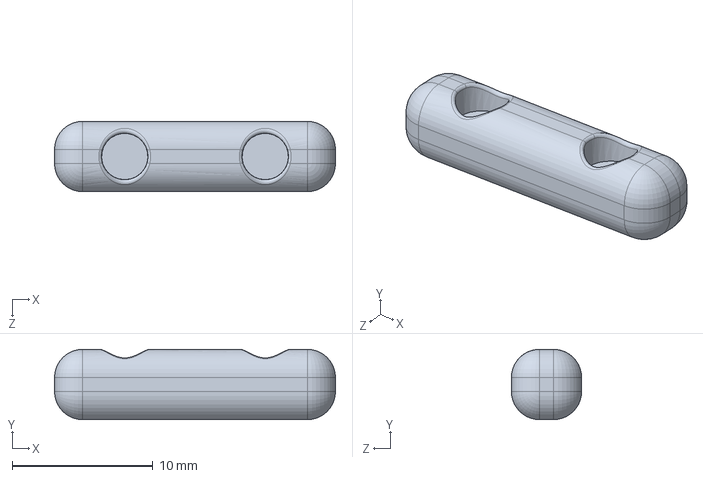
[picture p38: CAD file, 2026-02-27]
CAD/draw part/MouseLock.SLDPRT
20.0 x 5.00 x 5.00 mm

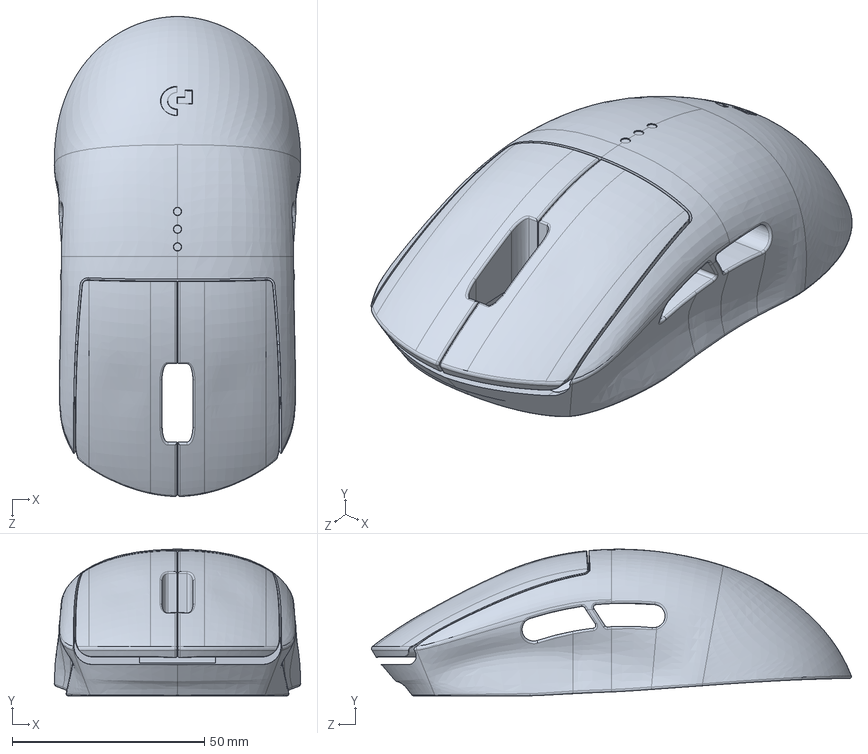
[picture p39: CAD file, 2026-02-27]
CAD/exist part/Mouse_Pro Wireless Gaming Mouse/body.SLDPRT
64.2 x 38.2 x 125.0 mm

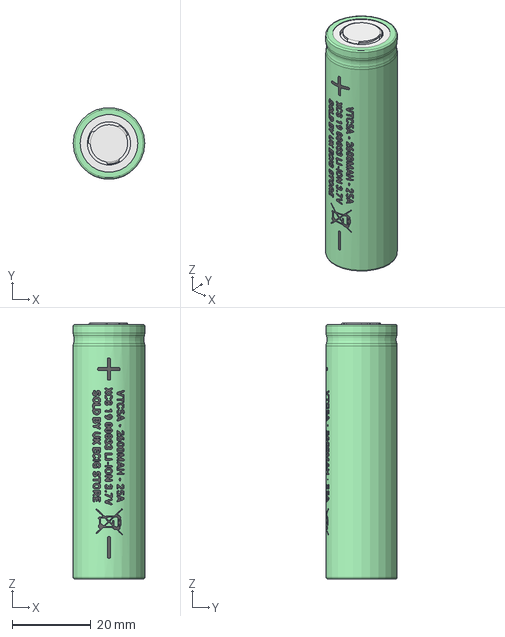
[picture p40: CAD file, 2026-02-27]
CAD/exist part/Sony Murata VTC5A 18650 2600mAh 25A Battery.step
18.2 x 18.1 x 65.0 mm
label

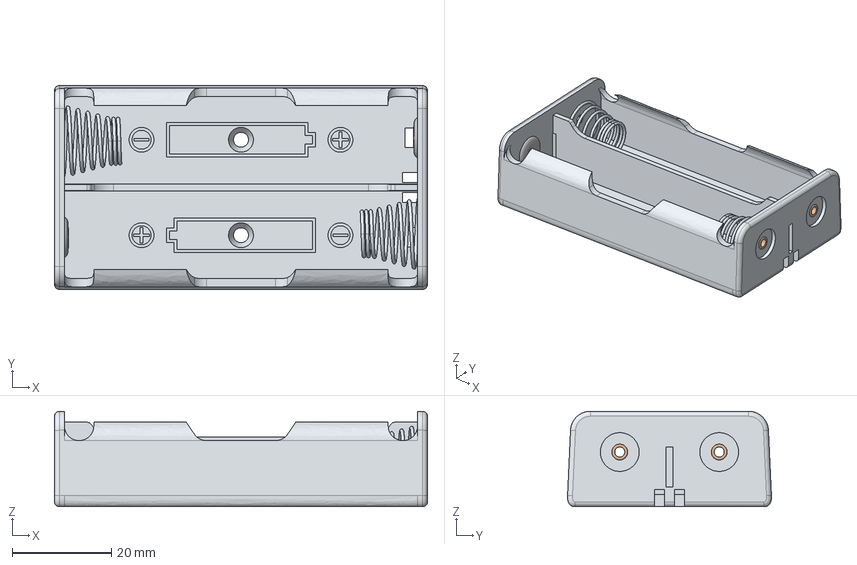
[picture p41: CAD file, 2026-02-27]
CAD/exist part/batteryCase18650x2.step
75.0 x 41.0 x 19.2 mm
spring x 2
2_rivets_1
2_rivets_2
positif x 2

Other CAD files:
CAD/exist part/Mouse_Pro Wireless Gaming Mouse/Base.SLDPRT
CAD/exist part/Mouse_Pro Wireless Gaming Mouse/wheel.SLDPRT
CAD/exist part/XL4016E1 8A Buck Converter.STEP
CAD/exist part/PCB_ESP32-38Pines.step
CAD/exist part/Modulo_DRV8833_B.stp
CAD/exist part/Mouse_Pro Wireless Gaming Mouse/Mouse_Hero.SLDASM
CAD/exist part/Mouse_Pro Wireless Gaming Mouse/Mouse_Hero.x_b
CAD/exist part/TT Motor.step

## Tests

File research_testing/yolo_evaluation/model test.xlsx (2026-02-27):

10 sec 12 fps
name | detail | all frame | detected | no detectd frame
Close Fast Colosseum Robots No Shooting | ROBOT RUNNING AROUND NO DAMAGE | 120 | 120 | 0
[N] CLS Click Robots | ROBOT RUNNING AROUND DAMAGE | 119 | 119 | 0
RoboTS180 | MANY ROBOT RUNNING AROUNG WITH DAMAGE | 119 | 322 | 3
Cata IC Fast Strafes Robot | robot running with damage but different environment | 119 | 108 | 11
Close Fast Strafes Invincivle OW Robot | very close running no damage | 120 | 120 | 0

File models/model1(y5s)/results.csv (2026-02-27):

epoch | train/box_loss | train/obj_loss | train/cls_loss | metrics/precision | metrics/recall | metrics/mAP_0.5 | metrics/mAP_0.5:0.95 | val/box_loss | val/obj_loss | val/cls_loss | x/lr0 | x/lr1 | x/lr2
0 | 0.048383 | 0.0092085 | 0 | 0.13326 | 0.17197 | 0.063833 | 0.026783 | 0.078074 | 0.048125 | 0 | 0.070077 | 0.0033248 | 0.0033248
1 | 0.038047 | 0.0070338 | 0 | 0.00076529 | 0.0075758 | 0.00014127 | 3.4473e-05 | 0.11665 | 0.028388 | 0 | 0.040011 | 0.0065922 | 0.0065922
2 | 0.036798 | 0.006975 | 0 | 0.61738 | 0.27083 | 0.28899 | 0.15167 | 0.070131 | 0.02335 | 0 | 0.0098789 | 0.0097936 | 0.0097936
3 | 0.032987 | 0.0063833 | 0 | 0.94543 | 0.37992 | 0.52075 | 0.25807 | 0.060918 | 0.023966 | 0 | 0.009703 | 0.009703 | 0.009703
4 | 0.030361 | 0.0061521 | 0 | 0.21041 | 0.36894 | 0.29191 | 0.14769 | 0.073851 | 0.029334 | 0 | 0.009703 | 0.009703 | 0.009703
5 | 0.029975 | 0.0060738 | 0 | 0.93876 | 0.49354 | 0.61906 | 0.30675 | 0.044927 | 0.023576 | 0 | 0.009604 | 0.009604 | 0.009604
6 | 0.028505 | 0.0059625 | 0 | 0.90006 | 0.6959 | 0.79458 | 0.46492 | 0.040124 | 0.016102 | 0 | 0.009505 | 0.009505 | 0.009505
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

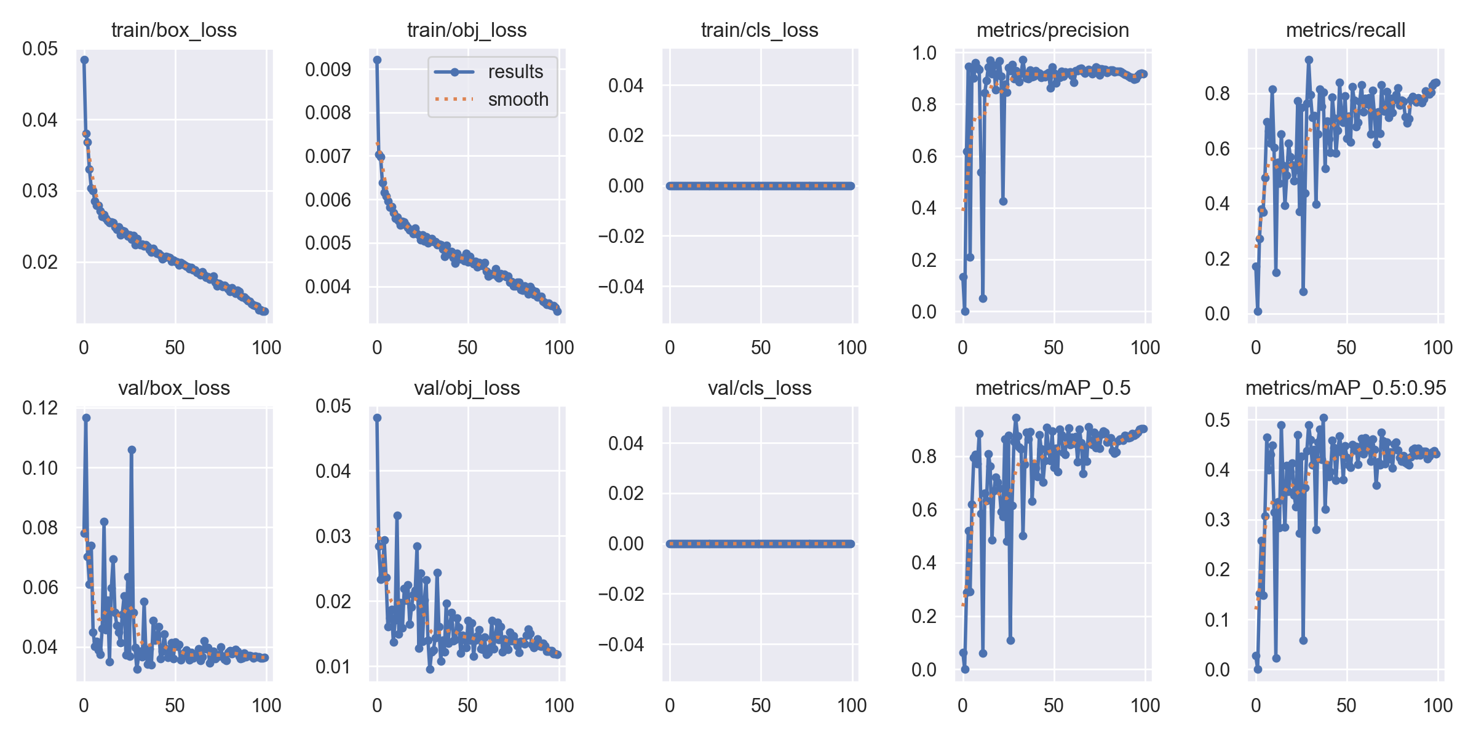
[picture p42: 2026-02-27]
models/model1(y5s)/results.png

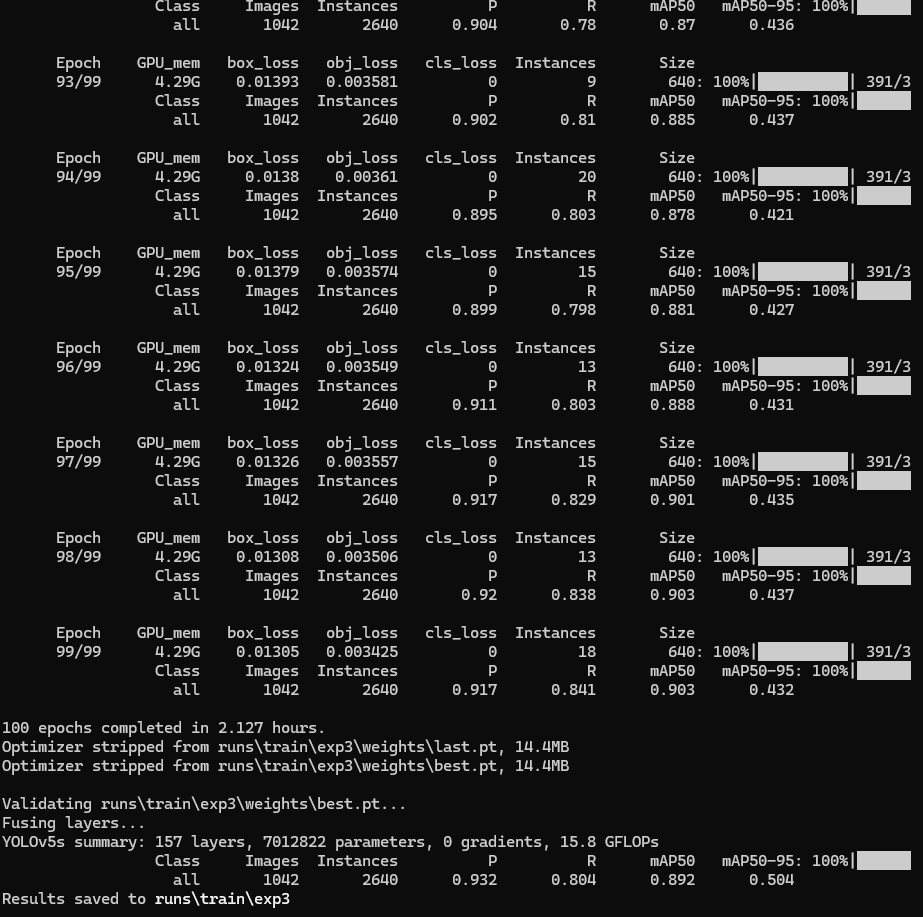
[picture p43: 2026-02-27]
model_evaluation/dataset_v1_baseline/train result.png

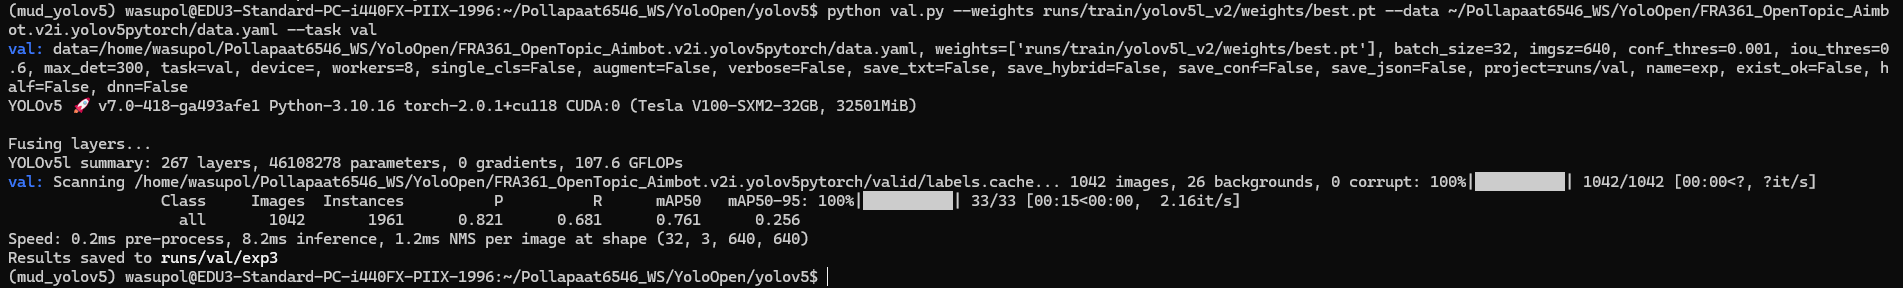
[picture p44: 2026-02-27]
model_evaluation/high_complexity_models/Lvalidation.png

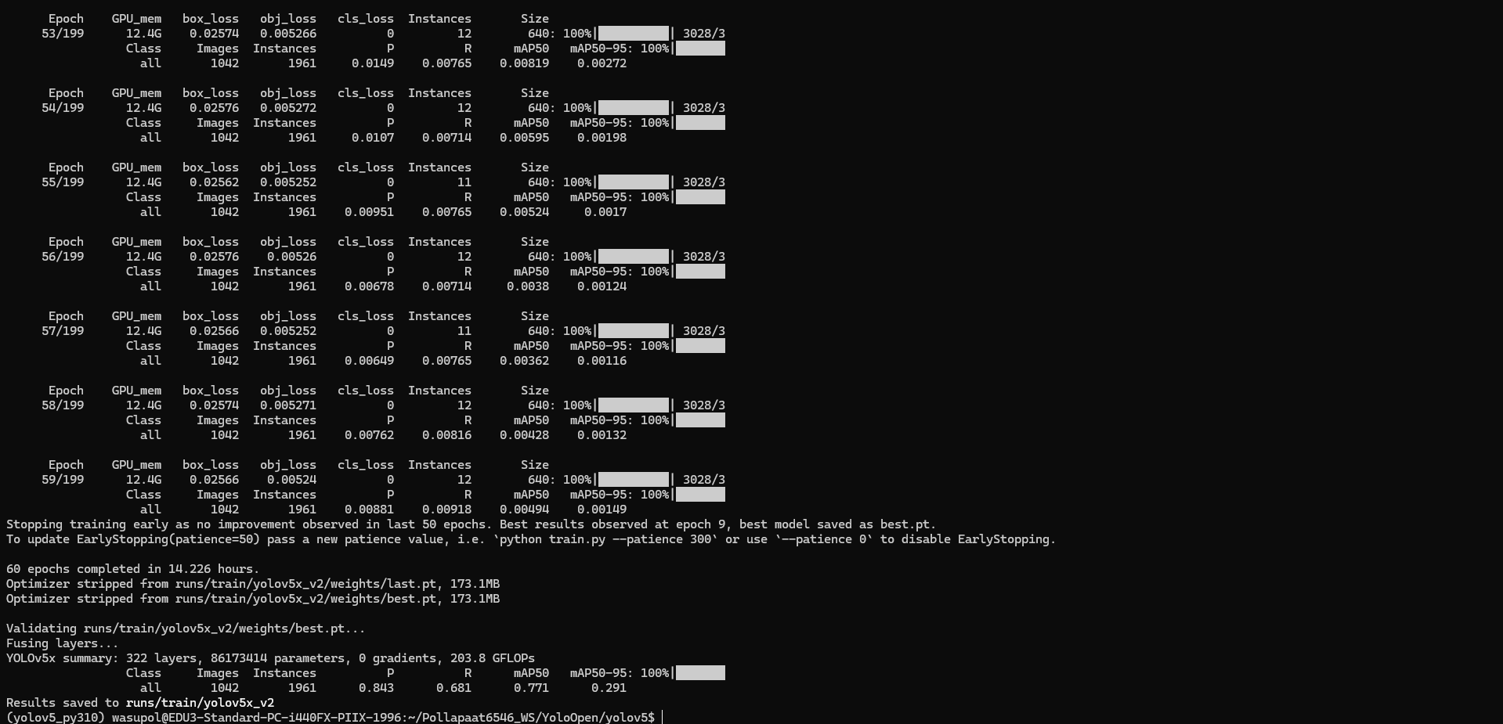
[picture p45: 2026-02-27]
model_evaluation/high_complexity_models/xtrainfinish.png

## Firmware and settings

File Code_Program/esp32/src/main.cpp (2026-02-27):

#include <Arduino.h>

// ==========================
// Pin configuration
// ==========================
// unsigned long lastMicros = 0;
// Front Left Motor
#define FL_IN1 25
#define FL_IN2 26

// Front Right Motor
#define FR_IN1 27
#define FR_IN2 14

// Back Left Motor
#define BL_IN1 12
#define BL_IN2 13

// Back Right Motor
#define BR_IN1 32
#define BR_IN2 33

// ==========================
// PWM configuration
// ==========================
const int PWM_FREQ       = 5000;  // 5 kHz PWM
const int PWM_RESOLUTION = 8;     // 8-bit (0–255)

// Channels for each IN1/IN2 pair
enum {
  CH_FL_F = 0, CH_FL_R,
  CH_FR_F, CH_FR_R,
  CH_BL_F, CH_BL_R,
  CH_BR_F, CH_BR_R
};

// Last commanded wheel PWMs (–255…+255)
int fl_pwm = 0, fr_pwm = 0, bl_pwm = 0, br_pwm = 0;

/**
 * Map percent input (–100…+100) to PWM:
 *   pct ==  0   →   0
 *   pct == +1   → +155
 *   pct == +100 → +255
 *   pct == –1   → –155
 *   pct == –100 → –255
 */
int percentToPwm(int pct) {
  if (pct > 0) {
    // map [1..100] → [155..255]
    //return map(pct, 1, 100, 155, 255);
    return map(pct, 1, 100, 133, 255);
  } else if (pct < 0) {
    // map [–1..–100] → [–145..–255]
    // map() needs increasing ranges, so flip:
    int absPct = -pct;
    //int pwm    = map(absPct, 1, 100, 155, 255);
    int pwm    = map(absPct, 1, 100, 133, 255);
    return -pwm;
  }
  // pct == 0
  return 0;
}

// Drive a single motor: chF = forward channel, chR = reverse channel
void driveMotor(int chF, int chR, int pwm) {
  if (pwm >= 0) {
    ledcWrite(chF, pwm);
    ledcWrite(chR, 0);
  } else {
    ledcWrite(chF, 0);
    ledcWrite(chR, -pwm);
  }
}

void setup() {
  Serial.begin(115200);
  while (!Serial) { delay(10); }
  Serial.println("ESP32 Wheel Sync with Deadzone Mapping Ready");

  // Configure pins as outputs
  pinMode(FL_IN1, OUTPUT); pinMode(FL_IN2, OUTPUT);
  pinMode(FR_IN1, OUTPUT); pinMode(FR_IN2, OUTPUT);
  pinMode(BL_IN1, OUTPUT); pinMode(BL_IN2, OUTPUT);
  pinMode(BR_IN1, OUTPUT); pinMode(BR_IN2, OUTPUT);

  // Attach each pin to a PWM channel
  ledcSetup(CH_FL_F, PWM_FREQ, PWM_RESOLUTION); ledcAttachPin(FL_IN1, CH_FL_F);
  ledcSetup(CH_FL_R, PWM_FREQ, PWM_RESOLUTION); ledcAttachPin(FL_IN2, CH_FL_R);

  ledcSetup(CH_FR_F, PWM_FREQ, PWM_RESOLUTION); ledcAttachPin(FR_IN1, CH_FR_F);
  ledcSetup(CH_FR_R, PWM_FREQ, PWM_RESOLUTION); ledcAttachPin(FR_IN2, CH_FR_R);

  ledcSetup(CH_BL_F, PWM_FREQ, PWM_RESOLUTION); ledcAttachPin(BL_IN1, CH_BL_F);
  ledcSetup(CH_BL_R, PWM_FREQ, PWM_RESOLUTION); ledcAttachPin(BL_IN2, CH_BL_R);

  ledcSetup(CH_BR_F, PWM_FREQ, PWM_RESOLUTION); ledcAttachPin(BR_IN1, CH_BR_F);
  ledcSetup(CH_BR_R, PWM_FREQ, PWM_RESOLUTION); ledcAttachPin(BR_IN2, CH_BR_R);
}

void loop() {
  // Read a line if available
  if (Serial.available()) {
    String line = Serial.readStringUntil('\n');
    line.trim();
    if (line.length() > 0) {
      int p0, p1, p2, p3;
      int n = sscanf(line.c_str(), "%d,%d,%d,%d", &p0, &p1, &p2, &p3);
      if (n == 4) {
        fl_pwm = percentToPwm(p0);
        fr_pwm = percentToPwm(p1);
        bl_pwm = percentToPwm(p2);
        br_pwm = percentToPwm(p3);
        Serial.printf(
          "Rx %%: [%d, %d, %d, %d] → PWM: [FL=%d, FR=%d, BL=%d, BR=%d]\n",
          p0, p1, p2, p3, fl_pwm, fr_pwm, bl_pwm, br_pwm
        );
      } else {
        Serial.println("! parse error");
      }
    }
  }

  // Re-apply last PWM values at 100 Hz
  driveMotor(CH_FL_F, CH_FL_R, fl_pwm);
  driveMotor(CH_FR_F, CH_FR_R, fr_pwm);
  driveMotor(CH_BL_F, CH_BL_R, bl_pwm);
  driveMotor(CH_BR_F, CH_BR_R, br_pwm);

    //   // record and echo timestamp
    // unsigned long now_us = micros();
    // Serial.printf("ACK %lu\n", now_us);
  delay(10);
}

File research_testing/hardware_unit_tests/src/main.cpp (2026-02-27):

#include <Arduino.h>

// ==========================
// Pin configuration
// ==========================

// Front Left Motor
#define FL_IN1 25
#define FL_IN2 26

// Front Right Motor
#define FR_IN1 27
#define FR_IN2 14

// Back Left Motor
#define BL_IN1 12
#define BL_IN2 13

// Back Right Motor
#define BR_IN1 32
#define BR_IN2 33

void setMotor(int in1, int in2, bool forward) {
  digitalWrite(in1, forward ? HIGH : LOW);
  digitalWrite(in2, forward ? LOW  : HIGH);
}

void stopAll() {
  digitalWrite(FL_IN1, LOW); digitalWrite(FL_IN2, LOW);
  digitalWrite(FR_IN1, LOW); digitalWrite(FR_IN2, LOW);
  digitalWrite(BL_IN1, LOW); digitalWrite(BL_IN2, LOW);
  digitalWrite(BR_IN1, LOW); digitalWrite(BR_IN2, LOW);
}

void setup() {
  pinMode(FL_IN1, OUTPUT); pinMode(FL_IN2, OUTPUT);
  pinMode(FR_IN1, OUTPUT); pinMode(FR_IN2, OUTPUT);
  pinMode(BL_IN1, OUTPUT); pinMode(BL_IN2, OUTPUT);
  pinMode(BR_IN1, OUTPUT); pinMode(BR_IN2, OUTPUT);
}

void loop() {
  // === เดินหน้า ===
  setMotor(FL_IN1, FL_IN2, true);
  setMotor(FR_IN1, FR_IN2, true);
  setMotor(BL_IN1, BL_IN2, true);
  setMotor(BR_IN1, BR_IN2, true);
  delay(500); stopAll(); delay(500);

  // === ถอยหลัง ===
  setMotor(FL_IN1, FL_IN2, false);
  setMotor(FR_IN1, FR_IN2, false);
  setMotor(BL_IN1, BL_IN2, false);
  setMotor(BR_IN1, BR_IN2, false);
  delay(500); stopAll(); delay(500);

  // === สไตรฟขวา ===
  setMotor(FL_IN1, FL_IN2, true);
  setMotor(FR_IN1, FR_IN2, false);
  setMotor(BL_IN1, BL_IN2, false);
  setMotor(BR_IN1, BR_IN2, true);
  delay(500); stopAll(); delay(500);

  // === สไตรฟซ้าย ===
  setMotor(FL_IN1, FL_IN2, false);
  setMotor(FR_IN1, FR_IN2, true);
  setMotor(BL_IN1, BL_IN2, true);
  setMotor(BR_IN1, BR_IN2, false);
  delay(500); stopAll(); delay(500);

  // === หมุนขวา ===
  setMotor(FL_IN1, FL_IN2, true);
  setMotor(FR_IN1, FR_IN2, false);
  setMotor(BL_IN1, BL_IN2, true);
  setMotor(BR_IN1, BR_IN2, false);
  delay(500); stopAll(); delay(500);

  // === หมุนซ้าย ===
  setMotor(FL_IN1, FL_IN2, false);
  setMotor(FR_IN1, FR_IN2, true);
  setMotor(BL_IN1, BL_IN2, false);
  setMotor(BR_IN1, BR_IN2, true);
  delay(500); stopAll(); delay(500);

  // === เฉียงหน้า-ขวา === (FL + BR forward)
  setMotor(FL_IN1, FL_IN2, true);
  setMotor(BR_IN1, BR_IN2, true);
  delay(500); stopAll(); delay(500);

  // === เฉียงหน้า-ซ้าย === (FR + BL forward)
  setMotor(FR_IN1, FR_IN2, true);
  setMotor(BL_IN1, BL_IN2, true);
  delay(500); stopAll(); delay(500);

  // === เฉียงหลัง-ขวา === (FR + BL backward)
  setMotor(FR_IN1, FR_IN2, false);
  setMotor(BL_IN1, BL_IN2, false);
  delay(500); stopAll(); delay(500);

  // === เฉียงหลัง-ซ้าย === (FL + BR backward)
  setMotor(FL_IN1, FL_IN2, false);
  setMotor(BR_IN1, BR_IN2, false);
  delay(500); stopAll(); delay(500);

  while (true) delay(1000); // หยุดลูปหลังทดสอบครบ
}

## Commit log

2026-02-27 Massive project overhaul: Added complete physical aimbot source code, CAD files, and updated requirements.
    [Base.SLDPRT, Basedown.SLDPRT, Buttons.SLDPRT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]
2026-02-27 Archive old logs and requirements; updated presentation and requirements.txt.
    [aimbot_log.csv, aimbot_log2.csv]
2026-02-27 Academic reorganization: Reorganized project structure into academic/readable folders and archived legacy files.
    [aimbot_log.csv, aimbot_log2.csv, hardware_bom.xlsx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]
2026-02-27 Build: Migrated ESP32 code to PlatformIO and finalized repository structure for Portfolio
